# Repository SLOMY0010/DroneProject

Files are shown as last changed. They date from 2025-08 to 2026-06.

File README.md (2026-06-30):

# DroneProject

Custom Arduino-based quadcopter controller system with a handheld Bluetooth controller, onboard stabilization algorithms, and KiCad PCB designs for both the drone electronics and the controller.

This project was developed as part of a summer program. The goal was to design and implement the main electronics and software required for a quadcopter prototype, including wireless control, sensor-based stabilization, motor mixing, safety behavior, and PCB design.

> **Project status:** Prototype / ground-tested.  
> The system was validated on the ground, but a complete stable flight test was not achieved within the project deadline. The final prototype was limited mainly by added weight, limited motor/frame lifting capacity, and the fact that the designed PCBs were not soldered and integrated before the final presentation.

## Demo

A demonstration video is available here:

[Drone Project: Custom Quadcopter Controller System](https://youtu.be/c0thseL-vnU)

## Overview

The system is divided into two main units:

1. **Drone unit**
   - Uses the frame and motors of an MJX Bugs 3 Pro drone.
   - Replaces the original electronics with a custom Arduino-based flight controller.
   - Reads IMU and compass data.
   - Applies Kalman filtering and PID control to stabilize roll, pitch, and yaw.
   - Drives four ESC-controlled brushless motors.
   - Includes safety behavior for lost communication and landing.

2. **Handheld controller unit**
   - Built around an Arduino Nano.
   - Reads joysticks, buttons, potentiometers, switches, and an MPU-6050 sensor.
   - Sends controller input packets to the drone over Bluetooth.
   - Supports normal joystick control and experimental gyro-based control modes.

```text
Handheld Controller                         Drone Unit
-------------------                         ----------
Joysticks / buttons / pots / IMU  --->  Bluetooth  --->  Arduino Nano
                                                        |
                                                        +--> IMU + compass
                                                        +--> Kalman filter
                                                        +--> PID controller
                                                        +--> Motor mixing
                                                        +--> ESCs / motors
```

## Main Features

- Arduino Nano based controller and drone firmware.
- Bluetooth communication between controller and drone.
- 18-byte controller data packet with checksum validation.
- Kalman-filtered roll and pitch angle estimation.
- PID stabilization for roll, pitch, and yaw.
- Magnetometer-based heading hold / north-facing behavior.
- Joystick control mode.
- Experimental gyro-control mode using the handheld controller orientation.
- Experimental potentiometer-based control mode.
- Motor mixing for a quadcopter X-style layout.
- Lost-signal safety behavior that slowly reduces throttle.
- Battery voltage indication using LEDs.
- KiCad PCB designs for the drone board and controller board.

## Repository Structure

```text
.
├── controller/
│   └── controller.ino
│       Firmware for the handheld controller.
│
├── drone_hardware_serial/
│   └── drone_hardware_serial.ino
│       Main drone firmware. This is the recommended drone-side version.
│       It uses the Arduino Nano hardware serial pins for Bluetooth communication,
│       which produced smoother motor behavior during testing.
│
├── drone/
│   └── drone.ino
│       Alternative drone firmware using SoftwareSerial for Bluetooth.
│       Useful for debugging because hardware Serial remains available for the
│       Arduino Serial Monitor. However, SoftwareSerial caused unstable motor
│       behavior during powered motor testing.
│
├── testing/
│   └── testing.ino
│       Experimental/testing code used during development.
│
├── PCB-Controller-main/
│       KiCad project files for the handheld controller PCB.
│
├── drone_pcb/
│       KiCad project files for the drone-side PCB.
│
└── Libraries/
        Shared KiCad symbols/footprints used by the PCB projects.
```

## Firmware Folders

### `controller/`

This folder contains the firmware uploaded to the Arduino Nano inside the handheld controller.

The controller reads:

- Two joysticks
- Four push buttons
- Two potentiometers
- Two switches
- MPU-6050 motion sensor

It packages the input data into a `Controller` struct and sends it to the drone through a Bluetooth module. The controller also performs joystick calibration and supports a gyro-control mode where the controller's tilt is used as a roll/pitch input.

### `drone_hardware_serial/`

This is the main drone firmware and the recommended version for actual motor testing.

It uses the Arduino Nano hardware serial interface for Bluetooth communication. This was more stable than the SoftwareSerial version when the motors were powered, because SoftwareSerial timing interfered with the control loop and produced unstable PWM behavior.

The firmware handles:

- Receiving controller packets over Bluetooth
- Validating received data using a checksum
- Reading IMU data
- Reading compass/magnetometer heading
- Kalman filtering for angle estimation
- PID control for stabilization
- Quadcopter motor mixing
- ESC PWM signal generation
- Battery LED indication
- Lost-communication landing behavior

### `drone/`

This is an older/alternative drone firmware version using SoftwareSerial for Bluetooth communication.

It is still useful for debugging because the hardware serial port remains available for the Serial Monitor. However, it is not the preferred version for powered motor testing because it caused unstable PWM behavior and stronger vibration during testing.

### `testing/`

This folder contains experimental code used while testing individual parts of the project.

## Communication Protocol

The controller sends a binary packet to the drone. The packet contains button states, joystick values, potentiometer values, gyro-mode roll/pitch values, and a checksum.

Simplified structure:

```cpp
struct Controller {
    uint8_t bools; // Buttons & switches
    int16_t roll, pitch; // MPU-6050 Readings
    int16_t JLx, JLy, JRx, JRy; // Joysticks input
    int16_t PL, PR; // Potentiometers
    uint8_t checksum; 
}; // 18-Bytes
```

The checksum is calculated using XOR over the packet bytes. On the drone side, packets are rejected if the checksum is invalid or if important values are outside expected limits.

The controller sends data when input changes and also sends periodic updates so the drone can detect that the connection is still alive.

## Control and Stabilization

The flight-control logic combines sensor reading, filtering, PID control, and motor mixing.

### Angle estimation

The drone uses accelerometer and gyroscope readings to estimate roll and pitch angles. A Kalman filter is used to combine the fast response of the gyroscope with the long-term correction of the accelerometer.

### PID control

PID controllers are used to reduce the difference between the target angle and the measured angle. The target angles come from either joystick input or gyro-mode controller input.

The PID outputs are then mixed into the motor signals to adjust the four motor speeds.

### Yaw / heading behavior

The drone firmware also reads magnetometer data to estimate heading. This allows heading hold behavior when there is no yaw input, and a mode for turning the drone toward north.

### Motor mixing

The drone uses four motors in a quadcopter layout:

```text
M1 = front-left
M2 = front-right
M3 = back-right
M4 = back-left
```

The firmware combines throttle, pitch, roll, and yaw values to generate the PWM signal for each motor.

## Hardware

### Drone unit

- MJX Bugs 3 Pro frame and motors
- Arduino Nano
- HW-290 sensor module
  - MPU-6050 accelerometer/gyroscope
  - Magnetometer
  - Barometer module available on the board, but not central to the current control code
- Bluetooth module
- Four ESCs
- Custom drone PCB design in KiCad
- Temporary breadboard circuit used during final testing

### Controller unit

- Arduino Nano
- Two joysticks
- Four push buttons
- Two potentiometers
- Two switches
- MPU-6050 sensor
- Bluetooth module
- Custom controller PCB design in KiCad
- Perfboard/breadboard prototype used during testing

## PCB Designs

The project includes KiCad PCB designs for both the drone and the controller.

- `PCB-Controller-main/` contains the controller PCB project.
- `drone_pcb/` contains the drone PCB project.
- `Libraries/` contains shared KiCad symbols and footprints required by the PCB projects.

The PCBs were designed and ordered, but they were not soldered, assembled, and fully tested before the project deadline. During the final testing stage, the electronics were still tested using a small breadboard mounted on the drone.

## Software Requirements

The code is written for the Arduino environment.

Expected tools/libraries:

- Arduino IDE or Arduino CLI
- Arduino Nano board support
- Standard Arduino libraries:
  - `Wire`
  - `Servo`
  - `SoftwareSerial`
- QMC5883L compass library or a compatible `QMC5883LCompass` library

Depending on the Arduino Nano board version, you may need to select either the normal ATmega328P bootloader or the old bootloader in the Arduino IDE.

## Upload Instructions

### 1. Upload the controller firmware

Open:

```text
controller/controller.ino
```

Upload it to the Arduino Nano used in the handheld controller.

### 2. Upload the recommended drone firmware

Open:

```text
drone_hardware_serial/drone_hardware_serial.ino
```

Upload it to the Arduino Nano used on the drone.

Because this version uses hardware serial for Bluetooth, disconnect the Bluetooth module from the Arduino Nano RX/TX pins while uploading if it interferes with programming.

### 3. Optional debugging firmware

For debugging, open:

```text
drone/drone.ino
```

This version uses SoftwareSerial for Bluetooth, leaving the hardware serial port available for the Arduino Serial Monitor. It is useful for troubleshooting, but it is not recommended for powered motor testing because SoftwareSerial caused unstable motor behavior during development.

## Safety Notes

This is an experimental drone-control project, not a ready-to-fly commercial flight controller.

Before testing:

- Remove propellers during firmware upload and initial motor tests.
- Secure the drone frame before powered tests.
- Verify motor order and direction.
- Verify ESC calibration and throttle range.
- Keep the drone level and still during sensor calibration.
- Test the lost-signal behavior before attempting flight.
- Do not attempt flight until the PID gains, wiring, power system, and mechanical setup are verified.

## Results

The project successfully implemented the main parts of a custom quadcopter control system:

- Wireless controller communication
- Controller input packaging
- Checksum-based packet validation
- IMU reading and calibration
- Kalman-filtered angle estimation
- PID-based stabilization logic
- Motor mixing and ESC signal generation
- PCB designs for both the controller and drone electronics

During ground testing, the electronics and algorithms responded correctly. However, stable flight was not achieved before the deadline. The main limitations were the added prototype weight, the limited lifting capacity of the reused frame/motors, and the fact that the final PCBs were not assembled and integrated in time.

## Known Limitations

- Full stable flight was not achieved.
- The drone was tested mainly on the ground.
- The PCBs were designed but not fully soldered and validated.
- The final test setup used a breadboard, which added weight and reduced reliability.
- The reused MJX Bugs 3 Pro frame and motors had limited lifting capacity with the added custom electronics.
- Bluetooth is not ideal for a final drone communication system.
- PID values require further tuning on a lighter and more reliable hardware setup.
- The SoftwareSerial drone firmware should be treated as a debugging variant, not the recommended flight-control version.

## Future Improvements

Possible next steps:

- Assemble and test the designed PCBs.
- Move to a lighter airframe or higher-thrust motors.
- Replace Bluetooth with a more suitable radio-control communication system.
- Improve power distribution and reduce electrical noise.
- Tune the PID controller during controlled flight tests.
- Add proper mechanical mounting for the IMU to reduce vibration.
- Add camera support.
- Improve failsafe behavior and pre-flight checks.
- Add more documentation for wiring and calibration.

## Author

Abdulaziz Salem Ali Salem

Project supervisor: Dr. Sütő József

## License

No license has been specified yet. If you plan to reuse this code or hardware design, please contact the author.

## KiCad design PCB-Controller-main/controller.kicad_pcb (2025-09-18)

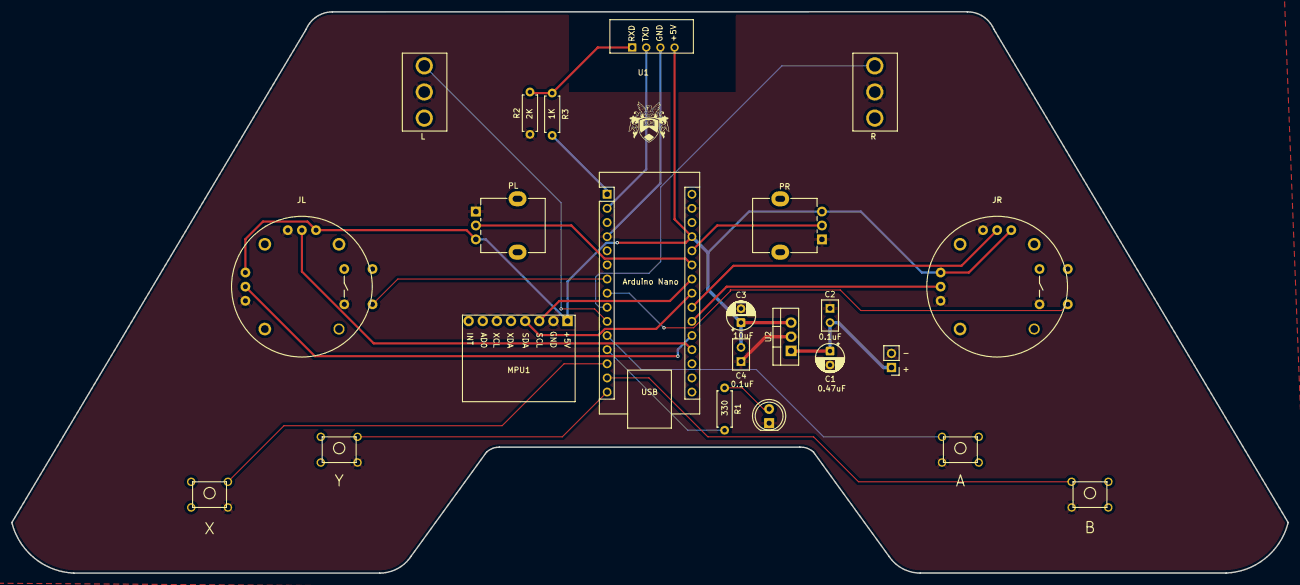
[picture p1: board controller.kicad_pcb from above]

Board: 2 copper layers, 229.5 x 100.9 mm, 23 parts (0 on the bottom side), 24 nets.

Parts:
A: SW_Push_Dual; BTN
Arduino Nano: Arduino_Nano_v3.x; Arduino_Nano
B: SW_Push_Dual; BTN
C1: 0.47uF; CP_Radial_D5.0mm_P2.50mm
C2, C4: 0.1uF; C
C3: 10uF; CP_Radial_D5.0mm_P2.50mm
D1: LED; LED_D5.0mm
J1: Conn_01x02_Pin; PinHeader_1x02_P2.54mm_Vertical
Joystick1, Joystick2: JOYSTICK
L: SW_SPDT; TOGGLE_SWITCH
MPU1: MPU6050
PL: R_Potentiometer; Potentiometer_Alpha_RD901F-40-00D_Single_Vertical
PR: R_Potentiometer; Potentiometer_Alpha_RD901F-40-00D_Single_Vertical
R: SW_SPDT; TOGGLE_SWITCH
R1: 330; R_Axial_DIN0207_L6.3mm_D2.5mm_P7.62mm_Horizontal
R2: 2K; R_Axial_DIN0207_L6.3mm_D2.5mm_P7.62mm_Horizontal
R3: 1K; R_Axial_DIN0207_L6.3mm_D2.5mm_P7.62mm_Horizontal
U1: HC-05
U2: L7805; TO-220-3_Vertical
X: SW_Push_Dual; BTN
Y: SW_Push_Dual; BTN

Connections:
+5V: Arduino Nano.27 (+5V), C3.1, C4.1, Joystick1.1 (VCC), Joystick1.4 (VCC), Joystick2.1 (VCC), Joystick2.4 (VCC), MPU1.1 (VCC), PL.3, PR.3, U1.4 (5V), U2.3 (OUT)
GND: A.3, Arduino Nano.4 (GND), Arduino Nano.29 (GND), B.3, C1.2, C2.2, C3.2, C4.2, D1.1 (K), J1.2, Joystick1.3 (GND), Joystick1.6 (GND), Joystick1.8 (GND), Joystick2.3 (GND), Joystick2.6 (GND), Joystick2.8 (GND), L.2 (B), MPU1.2 (GND), PL.1, PR.1, R.2 (B), R2.1, U1.3 (GND), U2.2 (GND), X.4, Y.4
unnamed: Arduino Nano.19 (A0), Joystick1.5 (VOUT)
unnamed: Arduino Nano.20 (A1), Joystick1.2 (VOUT)
unnamed: Arduino Nano.21 (A2), Joystick2.2 (VOUT)
unnamed: Arduino Nano.22 (A3), Joystick2.5 (VOUT)
unnamed: Arduino Nano.23 (A4), MPU1.4 (SDA)
unnamed: Arduino Nano.24 (A5), MPU1.3 (SCL)
unnamed: Arduino Nano.25 (A6), PL.2
unnamed: Arduino Nano.26 (A7), PR.2
unnamed: Arduino Nano.2 (D0/RX), U1.2 (TXD)
unnamed: Arduino Nano.1 (D1/TX), R3.2
unnamed: Arduino Nano.7 (D4), Joystick1.9 (DOUT)
unnamed: Arduino Nano.8 (D5), Joystick2.9 (DOUT)
unnamed: Arduino Nano.9 (D6), R.3 (C)
unnamed: Arduino Nano.10 (D7), L.3 (C)
unnamed: A.1, Arduino Nano.11 (D8)
unnamed: Arduino Nano.12 (D9), R1.2
unnamed: Arduino Nano.13 (D10), X.2
unnamed: Arduino Nano.14 (D11), B.1
unnamed: Arduino Nano.15 (D12), Y.2
unnamed: D1.2 (A), R1.1
unnamed: R2.2, R3.1, U1.1 (RXD)
VCC: C1.1, C2.1, J1.1, U2.1 (IN)

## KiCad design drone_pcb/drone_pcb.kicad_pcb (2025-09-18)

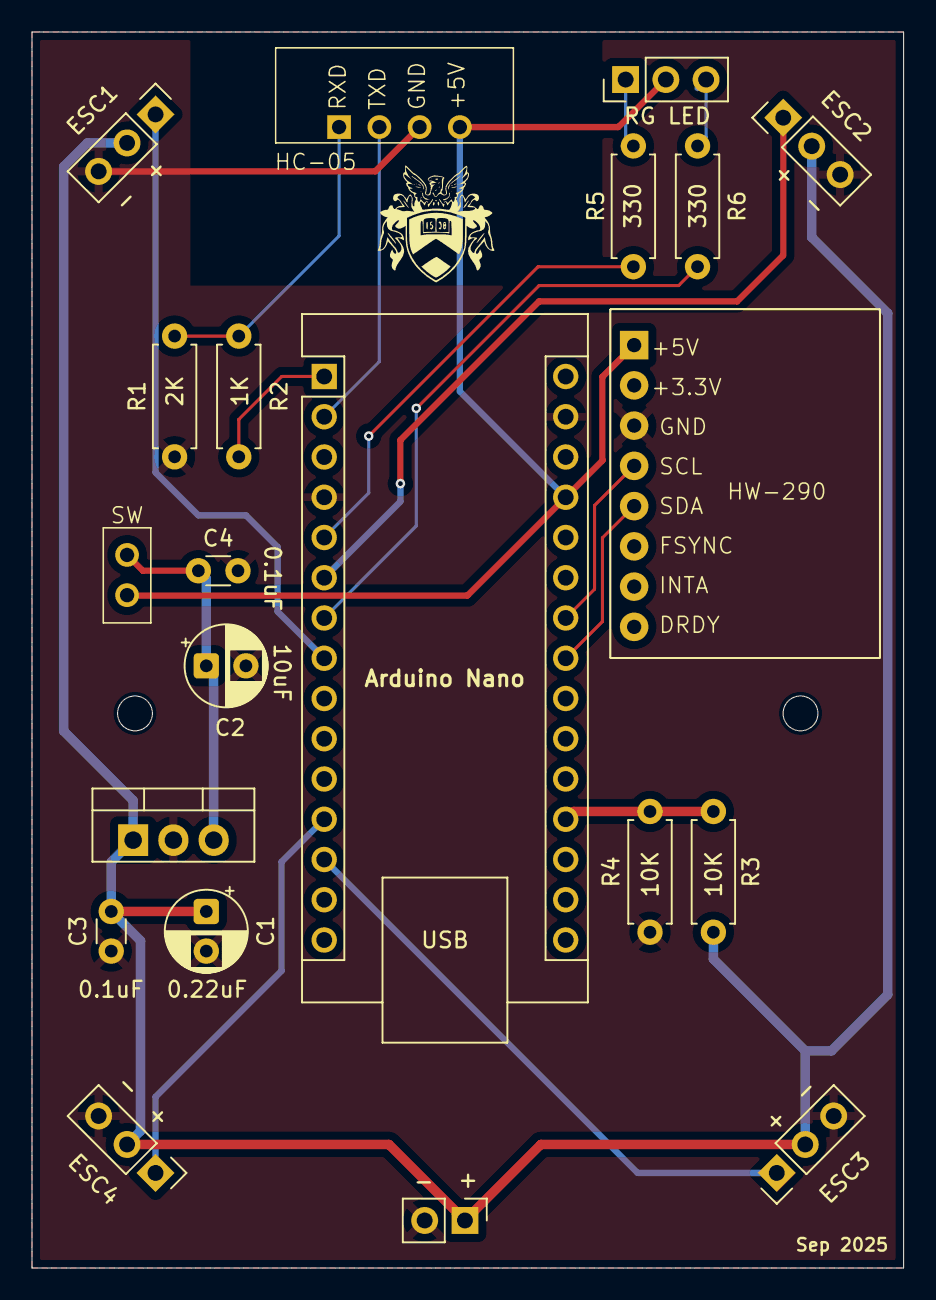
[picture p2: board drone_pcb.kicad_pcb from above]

Board: 2 copper layers, 55.0 x 78.0 mm, 21 parts (0 on the bottom side), 18 nets.

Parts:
Arduino Nano: Arduino_Nano_v3.x; Arduino_Nano
C1: 0.22uF; CP_Radial_D5.0mm_P2.50mm
C2: 10uF; CP_Radial_D5.0mm_P2.50mm
C3, C4: 0.1uF; C_Disc_D3.0mm_W1.6mm_P2.50mm
ESC1, ESC2, ESC3, ESC4: 3-pin Header; PinHeader_1x03_P2.54mm_Vertical
HC-05: HC-05
HW-290: HW-290
J1: Conn_01x02_Pin; PinHeader_1x02_P2.54mm_Vertical
R1: 2K; R_Axial_DIN0207_L6.3mm_D2.5mm_P7.62mm_Horizontal
R2: 1K; R_Axial_DIN0207_L6.3mm_D2.5mm_P7.62mm_Horizontal
R3, R4: 10K; R_Axial_DIN0207_L6.3mm_D2.5mm_P7.62mm_Horizontal
R5, R6: 330; R_Axial_DIN0207_L6.3mm_D2.5mm_P7.62mm_Horizontal
RG LED: RG LED; PinHeader_1x03_P2.54mm_Vertical
SW: SW_SPST; SW_reg5v
U7: L7805; TO-220-3_Vertical

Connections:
+5V: Arduino Nano.27 (+5V), HC-05.4 (5V), HW-290.1 (5V), RG LED.2 (VCC), SW.2 (B)
GND: Arduino Nano.4 (GND), Arduino Nano.29 (GND), C1.2, C2.2, C3.2, C4.2, ESC1.3 (GND), ESC2.3 (GND), ESC3.3 (GND), ESC4.3 (GND), HC-05.3 (GND), HW-290.3 (GND), J1.2, R1.1, R4.2, U7.2 (GND)
unnamed: Arduino Nano.19 (A0), R3.1, R4.1
unnamed: Arduino Nano.23 (A4), HW-290.5 (SDA)
unnamed: Arduino Nano.24 (A5), HW-290.4 (SCL)
unnamed: Arduino Nano.2 (D0/RX), HC-05.2 (TXD)
unnamed: Arduino Nano.1 (D1/TX), R2.1
unnamed: Arduino Nano.5 (D2), R5.1
unnamed: Arduino Nano.6 (D3), ESC2.1 (SIG)
unnamed: Arduino Nano.7 (D4), R6.1
unnamed: Arduino Nano.8 (D5), ESC1.1 (SIG)
unnamed: Arduino Nano.12 (D9), ESC4.1 (SIG)
unnamed: Arduino Nano.13 (D10), ESC3.1 (SIG)
unnamed: C2.1, C4.1, SW.1 (A), U7.3 (OUT)
unnamed: HC-05.1 (RXD), R1.2, R2.2
unnamed: R6.2, RG LED.3 (G)
unnamed: R5.2, RG LED.1 (R)
VCC: C1.1, C3.1, ESC1.2 (VCC), ESC2.2 (VCC), ESC3.2 (VCC), ESC4.2 (VCC), J1.1, R3.2, U7.1 (IN)

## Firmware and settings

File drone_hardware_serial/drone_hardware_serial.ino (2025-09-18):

#include <Servo.h>
#include <SoftwareSerial.h>
#include <Wire.h>
#include <QMC5883LCompass.h>

#define MAX_SPEED 1800
#define MIN_SPEED 1000
#define MAX_ANGLE_INPUT 30
#define MIN_ANGLE_INPUT -30
#define BATTERY_PIN A7
#define BAT_R_LED 4
#define BAT_G_LED 6

// Bools masks. For all boolean inputs.
#define BTN_X 0x01  // 0000 0001
#define BTN_Y 0x02  // 0000 0010
#define BTN_A 0x04  // 0000 0100
#define BTN_B 0x08  // 0000 1000
#define JBTN_L 0x10 // 0001 0000
#define JBTN_R 0x20 // 0010 0000
#define SW_L 0x40   // 0100 0000
#define SW_R 0x80   // 1000 0000

// MPU-6050 registers
#define MPU6050_ADDR 0x68
#define PWR_MGMT_1 0x6B
#define USER_CTRL 0x6A
#define INT_PIN_CFG 0x37

#define PID_SCALE_FACTOR 2.5 // This is used to scale the PID output to proper motor signal

// This struct is used to reconstruct the data sent by the controller
struct Controller {
  uint8_t bools;
  int16_t roll, pitch;
  int16_t JLx, JLy, JRx, JRy;
  int16_t PL, PR;
  uint8_t checksum;
};

// To set time global variables
unsigned long now_millis = millis();
unsigned long now_micros = micros();

/************** Global Variables **************/
int throttle = 0; 
unsigned long data_waiting_time = 3000; // The drone will wait for this amoung of milliseconds to receive from the controller, if it does not receive, it will land
unsigned long last_received = now_millis;
bool transmission_started = false; 

Servo M1, M2, M3, M4; // Motors configuration: M1 front-left, M2 front-right, M3 back-right, M4 back-left.
//SoftwareSerial BT(2, 7); // Bluetooth module TX -> 2 RX -> 7

// For gyroscope calibration
float gyro_x_bias = 0;
float gyro_y_bias = 0;
float gyro_z_bias = 0;

// For accelerometer calibration
float acc_x_bias = 0;
float acc_y_bias = 0;
float acc_z_bias = 0;

// For the Kalman filter

  unsigned long last_time_kf = now_micros;

  // For roll
  float angle_roll = 0.0;
  float bias_roll = 0.0;
  float P_roll[2][2] = { {1, 0}, {0, 1} };

  // For pitch
  float angle_pitch = 0.0;
  float bias_pitch = 0.0;
  float P_pitch[2][2] = { {1, 0}, {0, 1} };

  // Kalman tuning constants (shared)
  float Q_angle = 0.004;
  float Q_bias  = 0.003;
  float R_measure = 0.04;

  float gy_roll, gy_yaw, gy_pitch; // Stores rotation rates in each axis (angular velocity)
  float acc_roll, acc_yaw, acc_pitch; // Stores acceleration in each axis

// For PID control
  // For roll
  float target_roll = 0.0;
  float prev_error_roll = 0.0;
  float integral_roll = 0.0;

  float Kp_roll = 1.0;
  float Ki_roll = 0.05;
  float Kd_roll = 0.02;

  unsigned long last_time_pid_roll = now_micros;

  // For pitch
  float target_pitch = 0.0;
  float prev_error_pitch = 0.0;
  float integral_pitch = 0.0;

  float Kp_pitch = 1.0;
  float Ki_pitch = 0.05;
  float Kd_pitch = 0.02;

  unsigned long last_time_pid_pitch = now_micros;

  // For yaw
  float target_yaw;
  float prev_error_yaw = 0.0;
  float integral_yaw = 0.0;

  float Kp_yaw = 0.2;
  float Ki_yaw = 0.01;
  float Kd_yaw = 0;

  bool got_target_yaw = false;

  unsigned long last_time_pid_yaw = now_micros;

// For the Magnetometer (compass)
  QMC5883LCompass compass;
  float heading;
  float declination_angle = 6.1666;

// For X mode
  bool xmode_on = false;
  bool PL_engaged = false;
  bool PR_engaged = false;
  int old_throttle;

Controller data;
/***********************************************/


void setup() {
  pinMode(BAT_G_LED, OUTPUT);
  pinMode(BAT_R_LED, OUTPUT);
  // Set led to red
  analogWrite(BAT_G_LED, 255);
  analogWrite(BAT_R_LED, 0);

  data.JLy = MIN_SPEED;
  data.JLx = 0;
  data.JRx = 0;
  data.JRy = 0;
  data.bools = 0; // No gyro flight mode

  M1.attach(5); 
  M2.attach(3); 
  M3.attach(10);
  M4.attach(9); 

  M1.writeMicroseconds(2000); // Arm ESC with minimum throttle
  M2.writeMicroseconds(2000); // Arm ESC with minimum throttle
  M3.writeMicroseconds(2000); // Arm ESC with minimum throttle
  M4.writeMicroseconds(2000); // Arm ESC with minimum throttle
  delay(2000); // Give ESC time to arm

  M1.writeMicroseconds(1000); // Arm ESC with minimum throttle
  M2.writeMicroseconds(1000); // Arm ESC with minimum throttle
  M3.writeMicroseconds(1000); // Arm ESC with minimum throttle
  M4.writeMicroseconds(1000); // Arm ESC with minimum throttle
  delay(2000); // Give ESC time to arm

  Wire.setClock(400000); // For the MPU-6050
  Wire.begin();

  delay(250);

  // Activate the MPU-6050
  Wire.beginTransmission(0x68);
  Wire.write(0x6B);
  Wire.write(0x00);
  Wire.endTransmission(0x68);

  // MPU Configuration
  Wire.beginTransmission(0x68); // 0x68 is the address of the MPU-6050
  Wire.write(0x1A); // Configures the digital low-pass filter
  Wire.write(0x05); // Chooses a low-pass filter with 10Hz cuttoff frequency
  Wire.endTransmission();

  // Set sensetivity
  Wire.beginTransmission(0x68);
  Wire.write(0x1B);
  Wire.write(0x8); // Full scale range: 500 degs/s or LSB 65.5
  Wire.endTransmission();

  enable_mpu_bypass(); // To allow connect the magnetometer to the main I2C bus

  calibrate_gyro();
  calibrate_acc();
  compass.init();

  Serial.begin(9600);

  // Turn off LED to indicate end of setup
  analogWrite(BAT_G_LED, 255);
  analogWrite(BAT_R_LED, 255);
}


void loop() {

  battery_status(); // Checks battery voltage and update led color accordingly.

  // Save old data in case received data is corrupted
  Controller old_data = data;
  if (Serial.available() >= sizeof(Controller)) {
    Serial.readBytes(((char *) &data), sizeof(Controller)); // Read rest of data
    analogWrite(BAT_R_LED, 0);
    analogWrite(BAT_G_LED, 175);

    if (compute_checksum(data) == data.checksum) {
      last_received = millis();
      transmission_started = true;
    } else {
      data = old_data;
      analogWrite(BAT_R_LED, 255);
      analogWrite(BAT_G_LED, 255); // LED will blink if data was rejected
    }
  }

  if (transmission_started) {
    // This function handles all movement and calculations
    calculate_update_throttle();
  }

  // If 10s went by without receiving data, and the throttle have already been changed by previously received data, land the drone.
  if ((millis() - last_received >= data_waiting_time && transmission_started) || ((data.bools & BTN_B) ? 1 : 0)) { // Pressing B lands the drone
    descend();
  }
}


/**************************** Functions ****************************/

void enable_mpu_bypass() {

  // Disable I2C master (ensure aux bus can be bypassed)
  Wire.beginTransmission(MPU6050_ADDR);
  Wire.write(USER_CTRL);
  Wire.write(0x00); // I2C_MST_EN=0
  Wire.endTransmission();

  // Enable BYPASS_EN so AUX_DA/AUX_CL connect to SDA/SCL
  Wire.beginTransmission(MPU6050_ADDR);
  Wire.write(INT_PIN_CFG);
  Wire.write(0x02); // BYPASS_EN=1
  Wire.endTransmission();
  delay(10);

}

void calculate_update_throttle() {
  int m1, m2, m3, m4;

  // Pitch and Roll inputs are mapped to -30 to 30 degrees range
  int pitch_input = map(data.JRy, -200, 200, MIN_ANGLE_INPUT, MAX_ANGLE_INPUT), roll_input = map(data.JRx, -200, 200, MIN_ANGLE_INPUT, MAX_ANGLE_INPUT), yaw_input = data.JLx;
  throttle = data.JLy;

  // If SW_L is on, it means X mode is on
  // If X mode was just enabled, save old throttle in order to keep the drone stable
  if (!xmode_on && (data.bools & BTN_Y) ? 1 : 0) {
    old_throttle = throttle;
    xmode_on = true;
  }

  // If X mode is enabled check if PR is close enough to current throttle. If it is close it is ok to engage it.
  if ((data.bools & BTN_Y) ? 1 : 0) {
    if (abs(data.PR - old_throttle) <= 50) {
      PL_engaged = true;
    }
    if (PL_engaged) throttle = data.PR;
    else throttle = old_throttle;
    
  } else if (xmode_on && !((data.bools & BTN_Y) ? 1 : 0)) { // If X mode was just disabled, disengage PL
    if (abs(data.PR - data.JLy) <= 50) {
      throttle = data.JLy;
      PL_engaged = false;
      PR_engaged = false;
      xmode_on = false;
    } else {
      throttle = data.PR;
    }
  }


  // If A is pressed, gyro mode is enabled, roll and pitch joystick inputs are ignored.
  target_roll = (data.bools & BTN_A) ? data.roll / 100.0 : roll_input;
  target_pitch = (data.bools & BTN_A) ? data.pitch / 100.0 : pitch_input;

  // Get angles measurments using the Kalman Filter
  unsigned long current_time = micros();
  float dt = (current_time - last_time_kf) / 1000000.0;
  last_time_kf = current_time;

  read_gyro();
  read_acc();

  angle_roll = kalman_filter(acc_roll, gy_roll, dt, angle_roll, bias_roll, P_roll);
  angle_pitch = kalman_filter(acc_pitch, gy_pitch, dt, angle_pitch, bias_pitch, P_pitch);

  // Get PID output
  float pid_output_pitch = pid_update(target_pitch, angle_pitch, (current_time - last_time_pid_pitch) / 1000000.0, Kp_pitch, Ki_pitch, Kd_pitch, prev_error_pitch, integral_pitch);
  last_time_pid_pitch = current_time;
  float pid_output_roll = pid_update(target_roll, angle_roll, (current_time - last_time_pid_roll) / 1000000.0, Kp_roll, Ki_roll, Kd_roll, prev_error_roll, integral_roll);
  last_time_pid_roll = current_time;

  read_compass(); // Calculates and sets the heading variable

  // If X was pressed, drone must face north. Facing north will be interrupted if there is input on JLx
  if ((data.bools & BTN_X) ? 1 : 0) {
    target_yaw = 0.0; // North
    got_target_yaw = true;
  }

  // Since we are not controlling the angles of yaw directly, we will use PID only to keep the drone face the same direction, when there is no yaw input
  if (data.JLx == 0 && got_target_yaw == false) {
    target_yaw = heading;
    got_target_yaw = true;
  } else if (data.JLx != 0) {
    got_target_yaw = false;
  }

  if (got_target_yaw) {
    float pid_output_yaw = pid_update(
      (target_yaw > 180) ? target_yaw - 360 : target_yaw, 
      (heading > 180) ? heading - 360 : heading, 
      (current_time - last_time_pid_yaw) / 1000000.0, 
      Kp_yaw, Ki_yaw, Kd_yaw, 
      prev_error_yaw, 
      integral_yaw
    );

    yaw_input = (int) (constrain(pid_output_yaw, -30, 30) * PID_SCALE_FACTOR * 2);

    last_time_pid_yaw = current_time;
  }

  // Scale the pid output to proper motor signals:
  int roll = (int) (pid_output_roll * PID_SCALE_FACTOR);
  int pitch = (int) (pid_output_pitch * PID_SCALE_FACTOR);

  m1 = constrain(throttle + pitch + roll + yaw_input, MIN_SPEED, MAX_SPEED);   // Front-left
  m2 = constrain(throttle + pitch - roll - yaw_input, MIN_SPEED, MAX_SPEED);   // Front-right
  m3 = constrain(throttle - pitch - roll + yaw_input, MIN_SPEED, MAX_SPEED);   // Back-right
  m4 = constrain(throttle - pitch + roll - yaw_input, MIN_SPEED, MAX_SPEED);   // Back-left

  // If throttle input is off (minimum), ignore mixing equation, motors must be off
  if (throttle == MIN_SPEED) {
    m1 = m2 = m3 = m4 = MIN_SPEED;
  }
  // Serial.print("m1: "); Serial.print(m1); Serial.print("    m2: "); Serial.print(m2);
  // Serial.print("    m3: "); Serial.print(m3); Serial.print("    m4: "); Serial.println(m4);

  // Update the speed of each motor
  update_throttle(m1, m2, m3, m4);
}


float pid_update(float target, float measured_angle, float dt, float Kp, float Ki, float Kd, float &prev_error, float &integral) {
  float error = target - measured_angle;

  if (abs(error) < 0.5) integral = 0.0;

  integral += error * dt;

  float max_integral = 100;
  if (integral > max_integral) integral = max_integral;
  if (integral < -max_integral) integral = -max_integral;
  
  float derivative = (error - prev_error) / dt;

  float output = Kp * error + Ki * integral + Kd * derivative;

  prev_error = error;
  return output;
}


float kalman_filter(float acc_angle, float gyro_rate, float dt, float &angle, float &bias, float P[2][2]) {

  // Prediction step
  angle += dt * (gyro_rate - bias);

  // Update error covariance
  P[0][0] += dt * (dt * P[1][1] - P[1][0] - P[0][1] + Q_angle);
  P[0][1] -= dt * P[1][1];
  P[1][0] -= dt * P[1][1];
  P[1][1] += Q_bias * dt;

  // Calculate the Kalman gain
  float S = P[0][0] + R_measure;
  float K[2];
  K[0] = P[0][0] / S;
  K[1] = P[1][0] / S;

  // Measurement update
  float y = acc_angle - angle;
  angle += K[0] * y;
  bias  += K[1] * y;

  // Update P
  float P00_temp = P[0][0];
  float P01_temp = P[0][1];

  P[0][0] -= K[0] * P00_temp;
  P[0][1] -= K[0] * P01_temp;
  P[1][0] -= K[1] * P00_temp;
  P[1][1] -= K[1] * P01_temp;

  return angle;
}


void update_throttle(int m1, int m2, int m3, int m4) {
  M1.writeMicroseconds(m1);
  M2.writeMicroseconds(m2);
  M3.writeMicroseconds(m3);
  M4.writeMicroseconds(m4);
}


void read_gyro() {
  // To store raw data from the gyroscope
  int16_t gyro_x;
  int16_t gyro_y;
  int16_t gyro_z;

  

  // Read rotation rates from the gyroscope
  Wire.beginTransmission(0x68);
  Wire.write(0x43);
  Wire.endTransmission();
  Wire.requestFrom(0x68, 6);

  gyro_x = Wire.read() << 8 | Wire.read();
  gyro_y = Wire.read() << 8 | Wire.read();
  gyro_z = Wire.read() << 8 | Wire.read();

  // Rates:
  // TODO if the chip is placed properly on the PCB, swap gy_roll and gy_pitch
  gy_pitch = (float) gyro_x / 65.5; // Notice that we're not subracting the bias, because the Kalman filter should handle it
  gy_roll = (float) gyro_y / 65.5;
  gy_yaw = (float) gyro_z / 65.5;

  // Serial.print("Roll: "); Serial.print(gy_roll);
  // Serial.print("    Yaw: "); Serial.print(gy_yaw);
  // Serial.print("    Pitch: "); Serial.println(gy_pitch);

}


void read_acc() {
  // To store raw data from the accelerometer
  int16_t acc_x;
  int16_t acc_y;
  int16_t acc_z;

  // Read data from the accelerometer
  Wire.beginTransmission(0x68);
  Wire.write(0x1C);
  Wire.write(0x10);
  Wire.endTransmission();
  Wire.beginTransmission(0x68);
  Wire.write(0x3B);
  Wire.endTransmission();
  Wire.requestFrom(0x68,6);

  // Read bytes
  acc_x = Wire.read() << 8 | Wire.read();
  acc_y = Wire.read() << 8 | Wire.read();
  acc_z = Wire.read() << 8 | Wire.read();

  float acc_x_clean = (float) acc_x / 4096 - acc_x_bias; 
  float acc_y_clean= (float) acc_y / 4096 - acc_y_bias;
  float acc_z_clean = (float) acc_z / 4096 - acc_z_bias + 1; // Because when the drone is idle, it will have gravitational acceleration along the z axis

  // This calculates the angles by using the accelerometer
  // TODO change roll and pitch variable names, this is because the HW-290 unit is not placed in the right direction on the breadboard
  // Signs depend on the way the chip is mounted
  acc_pitch = atan2(acc_y_clean, sqrt(acc_x_clean * acc_x_clean + acc_z_clean * acc_z_clean)) * 180 / PI;
  acc_roll = -atan2(acc_x_clean, sqrt(acc_y_clean * acc_y_clean + acc_z_clean * acc_z_clean)) * 180 / PI;

  // Serial.print("Roll angle: "); Serial.print(roll_angle);
  // Serial.print("    Pitch angle: "); Serial.println(pitch_angle);

}


void read_compass() {
  // Read heading from compass
  compass.read();
  int mx = compass.getX(); int my = compass.getY(); int mz = compass.getZ();

  // Calibration values: -1062,2191,-757,2407,-1631,1736
  int mx_min = -1062, mx_max = 2191, my_min = -757, my_max = 2407, mz_min = -1631, mz_max = 1736;

  // Compute offsets
  float offset_x = (mx_max + mx_min) / 2.0, offset_y = (my_max + my_min) / 2.0, offset_z = (mz_max + mz_min) / 2.0;

  // Compute scale factors
  float range_x = (mx_max - mx_min) / 2.0, range_y = (my_max - my_min) / 2.0, range_z = (mz_max - mz_min) / 2.0;
  float avg_range = (range_x + range_y + range_z) / 3.0;

  // Scale and subtract offsets
  float mx_cal = (mx - offset_x) * (avg_range / range_x);
  float my_cal = (my - offset_y) * (avg_range / range_y);
  float mz_cal = (mz - offset_z) * (avg_range / range_z);

  float roll_rad = -angle_roll * PI / 180.0; float pitch_rad = -angle_pitch * PI / 180.0;

  float mxh = mx_cal * cos(pitch_rad) + mz_cal * sin(pitch_rad);
  float myh = mx_cal * sin(roll_rad) * sin(pitch_rad) + my_cal * cos(roll_rad) - mz_cal * sin(roll_rad) * cos(pitch_rad);

  heading = atan2(myh, mxh) * 180.0 / PI + declination_angle;
  if (heading < 0) heading += 360.0;
}


void calibrate_gyro() {
  long x_sum = 0, y_sum = 0, z_sum = 0;

  for (int i = 0; i < 2000; i++) {
    // Read data
    Wire.beginTransmission(0x68);
    Wire.write(0x43);
    Wire.endTransmission();

    Wire.requestFrom(0x68, 6);
    int16_t gx = Wire.read() << 8 | Wire.read();
    int16_t gy = Wire.read() << 8 | Wire.read();
    int16_t gz = Wire.read() << 8 | Wire.read();

    x_sum += gx;
    y_sum += gy;
    z_sum += gz;
  }
  gyro_x_bias = (float) x_sum / 2000;
  gyro_y_bias = (float) y_sum / 2000;
  gyro_z_bias = (float) z_sum / 2000;
}


void calibrate_acc() {
  long x_sum = 0, y_sum = 0, z_sum = 0;
  int samples = 200;

  for (int i = 0; i < samples; i++) {
    // Read data
    Wire.beginTransmission(0x68);
    Wire.write(0x3B);
    Wire.endTransmission();
    Wire.requestFrom(0x68, 6);

    int16_t acc_x = Wire.read() << 8 | Wire.read();
    int16_t acc_y = Wire.read() << 8 | Wire.read();
    int16_t acc_z = Wire.read() << 8 | Wire.read();

    x_sum += acc_x;
    y_sum += acc_y;
    z_sum += acc_z;
  }

  acc_x_bias = ((float) x_sum / samples) / 4069.0;
  acc_y_bias = ((float) y_sum / samples) / 4069.0;
  acc_z_bias = ((float) z_sum / samples) / 4069.0;
}


void descend() {
  unsigned long last_reduced_throttle = millis();
  bool led_blink = 1;

  // Reset inputs to focus on landing
  data.bools = 0; data.JLy = throttle; data.JLx = 0; data.JRx = 0; data.JRy = 0;
  
  while (throttle > MIN_SPEED) { // This loop imitates the loop() function, but data input is processed and throttle reduced to land the drone
    if (millis() - last_reduced_throttle >= 1000) {
      data.JLy -= 20;
      last_reduced_throttle = millis();

      // Blink the led while keeping the color respective to the battery status
      if (led_blink = !led_blink) {
        battery_status();
      } else {
        analogWrite(BAT_G_LED, 255);
        analogWrite(BAT_R_LED, 255);
      }
    }

    calculate_update_throttle();
  }

  // Reset throttle
  data.JLy = MIN_SPEED;
  throttle = MIN_SPEED;

  got_target_yaw = false;

  transmission_started = false;
}


// For validating data received from the controller
uint8_t compute_checksum(const Controller &data) {
  const uint8_t *ptr = (const uint8_t *) &data;
  uint8_t sum = 0;

  for (size_t i = 0; i < sizeof(Controller) - 1; ++i) 
    sum ^= ptr[i];

  // In case some data violates limits but still seems valid in the checksum, set checksum to 0 to reject it
  if (data.JLy < MIN_SPEED || data.JLy > MAX_SPEED ||
      data.JLx < -200 || data.JLx > 200 ||
      data.JRx < -200 || data.JRx > 200 ||
      data.JRy < -200 || data.JRy > 200 ||
      (data.roll / 100.0) < MIN_ANGLE_INPUT || (data.roll / 100.0) > MAX_ANGLE_INPUT ||
      (data.pitch / 100.0) < MIN_ANGLE_INPUT || (data.pitch / 100.0) > MAX_ANGLE_INPUT) 
    {
      return -1;  
    } 

  return sum;
}

void battery_status() {
  int pin_reading = analogRead(BATTERY_PIN);
  float pin_voltage = pin_reading * 5.0 / 1023.0;
  float battery_voltage = pin_voltage * 2; // Because the voltage devider is a 1/2 divider
  
  if (battery_voltage >= 7.4) {
    // 0 -> fully on, 255 -> fully off
    analogWrite(BAT_R_LED, 255);
    analogWrite(BAT_G_LED, 0);
  } else if (battery_voltage < 7.4 && battery_voltage > 7.0) {
    analogWrite(BAT_R_LED, 0);
    analogWrite(BAT_G_LED, 0);
  } else if (battery_voltage <= 7.0 && battery_voltage > 6.0) {
    analogWrite(BAT_R_LED, 0);
    analogWrite(BAT_G_LED, 175);
  } else if (battery_voltage <= 6.0) {
    analogWrite(BAT_R_LED, 0);
    analogWrite(BAT_G_LED, 255);
  }
}

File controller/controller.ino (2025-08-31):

#include <Wire.h>
#include <SoftwareSerial.h>

#define MAX_SPEED 1800 // Signal value for maximum motor speed is 1800us
#define MIN_SPEED 1000 // Signal value for minimum motor speed is 1000us
#define MAX_ANGLE_INPUT 30
#define MIN_ANGLE_INPUT -30

#define led 9

// Bools masks.
#define BTN_X 0x01 // 0000 0001
#define BTN_Y 0x02 // 0000 0010
#define BTN_A 0x04 // 0000 0100
#define BTN_B 0x08 // 0000 1000

// buttons pins
#define x_pin 10
#define y_pin 12
#define a_pin 8
#define b_pin 11

// This struct collects the controller data to send it to the drone
struct Controller {
  uint8_t bools;
  int16_t roll, pitch;
  int16_t JLx, JLy, JRx, JRy;
  int16_t PL, PR;
  uint8_t checksum;
};

/**************************** Global Variables ****************************/

bool new_input = false;

// To fix Joysticks' offset
int JLx_offset = 0, JLy_offset = 0, JRx_offset = 0, JRy_offset = 0;

// For gyroscope calibration
float gyro_x_bias = 0;
float gyro_y_bias = 0;
float gyro_z_bias = 0;

// For accelerometer calibration
float acc_x_bias = 0;
float acc_y_bias = 0;
float acc_z_bias = 0;

// For the Kalman filter

  unsigned long last_time_kf = micros();

  // For roll
  float angle_roll = 0.0;
  float bias_roll = 0.0;
  float P_roll[2][2] = { {1, 0}, {0, 1} };

  // For pitch
  float angle_pitch = 0.0;
  float bias_pitch = 0.0;
  float P_pitch[2][2] = { {1, 0}, {0, 1} };

  // Kalman tuning constants (shared)
  float Q_angle = 0.004;
  float Q_bias  = 0.003;
  float R_measure = 0.04;

  float gy_roll, gy_yaw, gy_pitch; // Stores rotation rates in each axis (angular velocity)
  float acc_roll, acc_yaw, acc_pitch; // Stores acceleration in each axis


// For buttons debouncing
unsigned long lastTimeXChanged = millis(), lastTimeYChanged = millis(), lastTimeAChanged = millis(), lastTimeBChanged = millis();
unsigned long debounceDuration = 100;
bool lastXState, lastYState, lastAState, lastBState;


SoftwareSerial BT(3, 2);  // Bluetooth module TX -> 3 RX -> 2

// For timing bluetooth transmission
unsigned long bt_last_sent = millis(); 
unsigned long bt_sending_interval = 50; // How often to send data to drone. in millis

// For gyro flying mode
unsigned long gymode_time = millis();
bool switched_gymode = false;
bool led_status = LOW;

// To package controller data
Controller data;

/***************************************************************************/


void setup() {
  /*
  * When the board is powered, the red LED will be on, meaning that the controller must not be touched because it is doing calibrations.
  * After those processes are done, the red LED will blink twice, then will stay on. After that, the throttle 
  * joystick (Left joystick) should be moved down to the zero and held at that position, after some seconds the LED
  * will turn on meaning that the controller starts working and will control the drone immediately. This is a safety measure.
  */

  digitalWrite(led, HIGH);

  data.JLx = 0;
  data.JLy = MIN_SPEED;
  data.JRx = 0;
  data.JRy = 0;;

  pinMode(led, OUTPUT);
  pinMode(x_pin, INPUT_PULLUP);
  pinMode(y_pin, INPUT_PULLUP);
  pinMode(a_pin, INPUT_PULLUP);
  pinMode(b_pin, INPUT_PULLUP);

  Serial.begin(9600);
  Wire.setClock(400000); // For the MPU-6050
  Wire.begin();

  delay(250);

  // Activate the MPU-6050
  Wire.beginTransmission(0x68);
  Wire.write(0x6B);
  Wire.write(0x00);
  Wire.endTransmission(0x68);

  // MPU Configuration
  Wire.beginTransmission(0x68); // 0x68 is the address of the MPU-6050
  Wire.write(0x1A); // Configures the digital low-pass filter
  Wire.write(0x05); // Chooses a low-pass filter with 10Hz cuttoff frequency
  Wire.endTransmission();

  // Set sensetivity
  Wire.beginTransmission(0x68);
  Wire.write(0x1B);
  Wire.write(0x8); // Full scale range: 500 degs/s or LSB 65.5
  Wire.endTransmission();


  // For buttons debouncing
  lastXState = digitalRead(x_pin);
  lastYState = digitalRead(y_pin);
  lastAState = digitalRead(a_pin);
  lastBState = digitalRead(b_pin);

  BT.begin(9600); // Begin bluetooth transmission.

  // Calibration processes
  delay(500);
  calculate_joysticks_offset();
  
  /*
  * The calibration above takes time, to ensure that the user doesn't change the state of the controller while calibrating,
  * the red LED will blink twice when the calibration is done and the controller is ready to use.
  */

  digitalWrite(led, LOW);
  delay(200);
  digitalWrite(led, HIGH);
  delay(200);
  digitalWrite(led, LOW);
  delay(200);
  digitalWrite(led, HIGH);

  // The Throttle Joystick must be at lowest position in order to start the code
  while (analogRead(A1) != 0) {
    delay(3000);
  }
  digitalWrite(led, LOW);
}


void loop() {
  
  // Get data from all input devices
  read_potens();
  read_joysticks();
  read_buttons();

  // If gyro flying mode is enabled, calculate roll and pitch angles
  if ((data.bools & BTN_A) ? 1 : 0) {
    if (switched_gymode == false) {
      switched_gymode = true;
      calibrate_gyro();
      calibrate_acc();
      gymode_time = millis();
      led_status = LOW;
    }

    // Blinks the led
    if (millis() - gymode_time >= 500) {
      gymode_time = millis();
      digitalWrite(led, !led_status);
      led_status = !led_status;
    }

    // For calculating pitch and roll angles
    float dt = (micros() - last_time_kf) / 1000000.0;
    last_time_kf = micros();
    
    read_gyro();
    read_acc();

    angle_roll = constrain(kalman_filter(acc_roll, gy_roll, dt, angle_roll, bias_roll, P_roll), MIN_ANGLE_INPUT, MAX_ANGLE_INPUT);
    angle_pitch = constrain(kalman_filter(acc_pitch, gy_pitch, dt, angle_pitch, bias_pitch, P_pitch), MIN_ANGLE_INPUT, MAX_ANGLE_INPUT);

    // Ignor joystick pitch and roll inputs
    data.JRx = 0;
    data.JRy = 0;

    data.roll = (int16_t) (angle_roll * 100);
    data.pitch = (int16_t) (angle_pitch * 100);

    new_input = true;

    // Serial.print("JLy: "); Serial.print(data.JLy);
    // Serial.print("    Roll: "); Serial.print(data.roll / 100.0);
    // Serial.print("    Pitch: "); Serial.println(data.pitch / 100.0);
  } else {
    switched_gymode = false;
    digitalWrite(led, LOW);
    led_status = LOW;
    data.roll = 0;
    data.pitch = 0;
  }

  // Serial.print("Rx: " ); Serial.print(data.JRx); Serial.print("  Ry: "); Serial.print(data.JRy);
  // Serial.print("    Lx: " ); Serial.print(data.JLx); Serial.print("  Ly: "); Serial.println(data.JLy);


  // Only send if there is change, if no change after sometime
  // send again to let the drone know that the connection is working
  if (new_input || millis() - bt_last_sent >= 1000) {
  // Send data to drone via bluetooth in each time interval
    if (millis() - bt_last_sent >= bt_sending_interval) {
      // Send data to drone:
      data.checksum = compute_checksum(data);
      BT.write((char *) &data, sizeof(Controller));
      bt_last_sent = millis();
      new_input = false;
      Serial.println("Sent");
    }
  }
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

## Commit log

2025-07-09 implemented speed calculation for each motor, and motion control
2025-07-13 Just fixed some comments
    [controller.ino, drone.ino]
2025-07-25 just made reading buttons update the new_input variable
2025-07-26 implemented accelerometer angle calculation, just from aeronautics
2025-07-31 finally implemented the kalman filter for measuring roll and pitch angles
2025-08-02 Finally figured out PID tunning
2025-08-04 fixed joystick calibration
2025-08-04 added gyro flying mode to fly the drone by moving the controller
2025-08-04 stopped before testing drone with the new PID and gyroscope code
2025-08-07 Tested bluetooth and gyro mode, next is testing with fans and pid tunning
2025-08-27 battery status
2025-08-27 button B lands the drone
2025-08-30 basic PID tunning is done
2025-08-30 gyro mode stopped working, I have no idea why. I'll fix it tomorrow
    [controller.ino, drone_hardware_serial.ino]
2025-08-31 Finally fixed gyro, and updated software serial version
    [controller.ino, drone.ino, drone_hardware_serial.ino]
2025-08-31 X mode is done for throttlegit status!
2025-09-18 Added PCB designs to the repository
    [controller.kicad_pcb, controller.kicad_sch, drone_pcb.kicad_pcb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]
